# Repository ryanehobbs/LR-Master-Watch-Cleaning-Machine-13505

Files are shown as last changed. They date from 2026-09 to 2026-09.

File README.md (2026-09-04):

# L&R Master Watch Cleaning Machine — Restoration (S/N 13505)

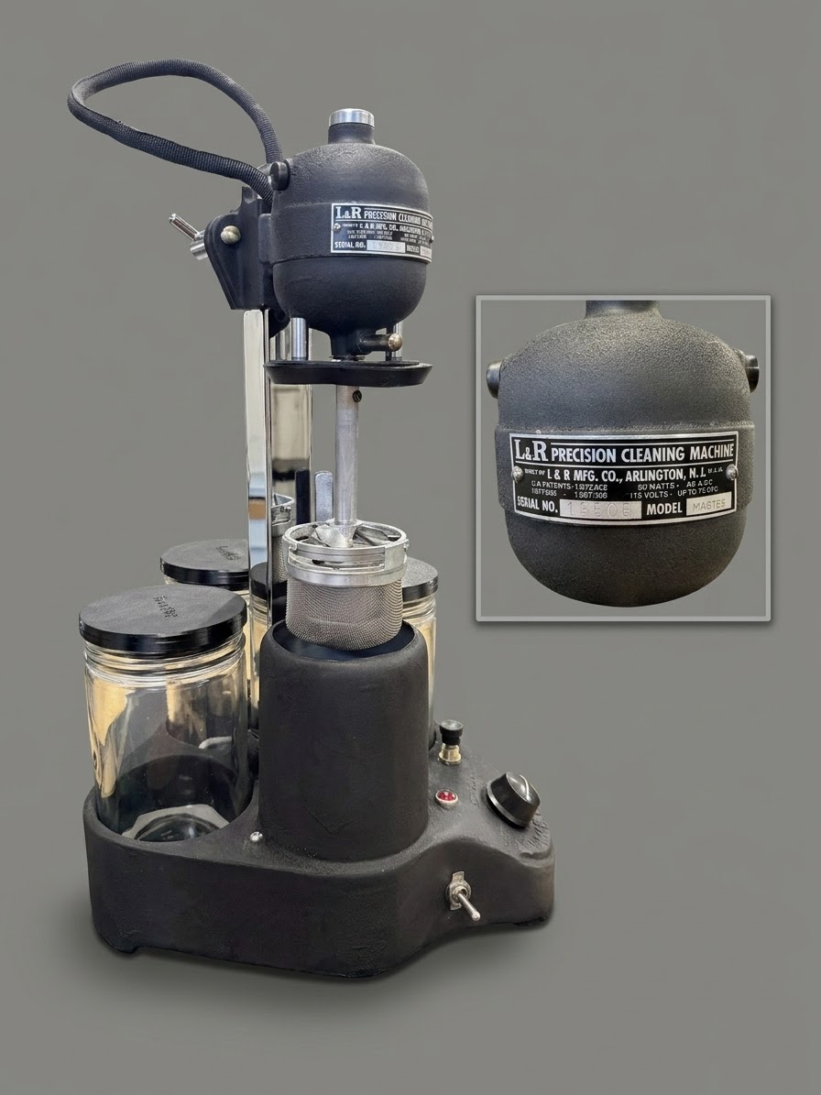
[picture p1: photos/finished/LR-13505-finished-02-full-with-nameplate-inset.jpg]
The restored L&R Precision Cleaning Machine, Model Master, Serial No. 13505 — fully rebuilt and working, with the motor-head data nameplate inset.


Open-source restoration and reverse-engineering of a vintage **L&R Mfg. Co. Master Watch Cleaning Machine** (Master, Serial 13505; the early oiled-bearing generation). This repository documents the full mechanical, cosmetic, and electrical restoration of the machine — from a seized, previously-modified relic to a **working, safely-grounded, fully-documented** cleaner — and contains a complete set of reverse-engineered engineering drawings and a three-part workshop manual, all produced from direct physical measurement of the specimen.

> **REPRODUCTION DOCUMENTATION** — Not original L&R Mfg. Co. technical publications. All drawings, dimensional data, and procedures were reverse-engineered from direct physical work on specimen S/N 13505. Curated by Hobbs R.E., 2026. For restoration reference only.

## Project Status

**🏁 The machine is fully restored and functional.** Both the motor/power head and the control unit are complete and bench-verified running on mains — the motor runs and reverses, the rheostat controls speed, the heater and pilot work, and the wiring passed a full cold-check before first power-on.

| Area | Status |
|---|---|
| **Mechanical restoration** | ✅ Complete — housing refinishing, ultrasonic cleaning, gasket conditioning, sleeve-bearing & wick overhaul, full reassembly |
| **Cosmetic refinishing** | ✅ Complete — motor housings + control-unit casting in VHT wrinkle finish; chrome re-plated; cast lettering restored |
| **Electrical** | ✅ Complete — meter-verified as-found circuit, then a **modern 3-wire grounded rewire** (silicone wire, Wago lever-nut junctions, chassis ground bond); Stage-0 cold-checks passed; commissioned |
| **Dimensional dataset** | ✅ Complete — motor/power head + control unit (base casting, carrier); all confidence-labeled |
| **Engineering drawings** | ✅ Complete — **16-sheet package** (component, exploded, and electrical) on a common master template |
| **Workshop manual** | ✅ First draft — all three parts (Operating / Maintenance / Restoration) |
| **Publication polish** | ⬜ In progress — manual compile, final photos, LICENSE + git init |

## The Machine

A vintage universal-series-motor watch cleaning machine: a mesh basket of disassembled watch parts is spun (forward and reverse) through solvent and rinse jars, then dried in a heated chamber. The motor head rides a swiveling carrier to index the basket over each station.

This restoration preserves the original mechanical character and appearance while **modernizing the electrical system for safety and serviceability** — the original was an ungrounded 2-wire design with a live "green" wire and no earth ground, and the specimen showed prior amateur rework. The rebuild adds a 3-wire grounded cord, a chassis ground bond, high-temp silicone wire, and serviceable lever-nut junctions; every deviation from original is documented.

Designed by **Frank Regero** and built by **L&R Mfg. Co.**; the machine embodies U.S. Patents **1,817,266** (1931), **1,872,812** (1932), and **1,907,366** (1933) — all verified, with copies and details in [`reference/patents/`](reference/patents/) (see [`reference/nameplate-and-patents.md`](reference/nameplate-and-patents.md)).

## Repository Layout

| Path | Contents |
|---|---|
| `docs/manual/` | **Workshop manual** — Part I (Operating), Part II (Maintenance & Service), Part III (Restoration), plus the as-performed source logs (`restoration-log.md`, `teardown-log.md`) |
| `docs/dimensions/` | Confirmed dimensional datasets (CSV) — parts dictionaries (BOM) + per-assembly measurements |
| `drawings/components/` | 2D engineering blueprints — motor components (UH / LH / BRG×2 / ARM / STR / HW / SPN / PLT / BSK), the motor-mount carrier (NCK-002), and the base casting (LR-BASE-001) |
| `drawings/exploded/` | Exploded assembly drawings — EXP-001 (2D profile) + EXP-002 (3D axonometric) |
| `drawings/electrical/` | Schematics — LR-ELEC-002 (verified as-found) + LR-ELEC-003 (as-built 3-wire grounded rewire) |
| `drawings/source/` | Plain-text (`.svg.txt`) snapshots of each drawing (1:1 with the live SVGs) |
| `photos/` | Bench documentation photos by subsystem (housing, armature, bearings, stator-wiring, gasket, basket, hardware, base-refinish, control-unit) |
| `reference/` | External reference material (vintage manuals, archive PDFs, styling references) |
| `archive/` | Superseded drafts and working material — **not part of the published project** (git-ignored) |
| `CLAUDE.md` | Master project log / engineering state (single source of truth) |

## Conventions

- Every physical component carries a canonical **Part ID** (e.g. `UH-003`, `ARM-006`, `STR-002`, `BAS-006`, `NCK-002`) defined in the parts dictionaries under `docs/dimensions/`. All drawings and docs reference parts by ID.
- Dimensions are labeled **(CONFIRMED)** / **(EST.)** / **(SYN)** / **(REF)** for measurement provenance.
- Because no original L&R manual for this machine was obtained, operating/maintenance procedures are labeled **best-judgment** (reconstructed from the mechanism), not factory-verified.
- Engineering-drawing pipeline: dimensions captured to CSV → drawings rendered on a 1200×800 master template → each kept as a `.svg.txt` source snapshot.

## License

Licensed under the **Creative Commons Attribution 4.0 International License (CC BY 4.0)** — see the [`LICENSE`](LICENSE) file. In short: you may use, adapt, and redistribute the material (including commercially), provided you give appropriate credit.

Suggested attribution: *"L&R Master Watch Cleaning Machine Restoration (S/N 13505) by Hobbs R.E., licensed under CC BY 4.0."*

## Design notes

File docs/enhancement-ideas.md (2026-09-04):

# Enhancement Ideas — Optional Modernizations (NON-ORIGINAL)

> **Parking lot, orthogonal to the main restoration.** These are *optional* electrical enhancements discussed as hypotheticals — **not** part of the faithful as-found restoration. None are committed. Guiding rule: **anything done here must keep the as-found design intact/restorable** (the verified `LR-ELEC-002` schematic is the reference), and everything must fold into the grounded, fused **R-5 rewire** — never the original 2-wire ungrounded scheme. Document any that get built as *enhancements*, clearly labeled non-original, in the shop manual.

Status legend: 💡 idea only · 🔬 evaluating · ✅ adopted into R-5 · ❌ declined

---

## 1. 💡 Automatic forward/reverse module
**Goal:** machine cycles motor forward ↔ reverse on its own, no operator input (manual plunger reversing still available).

**Why it's easy here:** reversing = which field lead is hot (white/a = forward, black/c = reverse), sharing one hot common. Anything that alternates hot between those two leads on a timer = auto-reverse. Rheostat (speed/OFF) and the armature/green return are untouched.

**Core:** one **SPDT relay** replicates the plunger (COM = hot, throws = white / black) + a **repeat-cycle timer** driving the coil.
- Timer options: (a) off-the-shelf adjustable **repeat-cycle timer relay** (cheapest); (b) **microcontroller (Arduino/ESP) + relay board** (most flexible); (c) **vintage cam/drum timer** (synchronous motor + cam — period-correct, more work).

**Engineering cautions (make it last):**
- **Coast pause between directions** — do NOT slam a spinning universal motor into reverse (big current spike + brush arcing). Sequence: forward → OFF (coast) → reverse → OFF → repeat.
- **Size relay contacts for INRUSH** (several× running), not just running current (<1 A bench). Suggest 8–10 A / 250 V contacts.
- **Snubber** across the contacts (RC) or an MOV — tames the inductive motor arc, big contact-life win.
- Mains-powered → on the grounded/fused R-5 system, enclosed.
- Optional: keep the manual plunger as a **manual/auto selector** or override.

---

## 2. 💡 Master power switch (fixes "always live when plugged in")
**Problem (documented):** no master switch — the hot rail (N2) is energized the moment the cord is plugged in; only the rheostat (motor) and toggle (heater) gate their branches.

**Fix:** a switch in the **HOT (line) conductor at the inlet, upstream of N2.** Open = whole machine dead.
- **Switch the HOT** specifically (not neutral). SPST in the hot leg = standard. **DPST** (hot + neutral) = full isolation, "belt and suspenders."
- Rheostat + heater toggle remain as downstream sub-controls (Master ON → then run motor / heater).
- **Sizing:** carries the TOTAL machine current — size for the sum with margin (~6–10 A / 250 V; measure total draw first).

**Recommended single-part solution:** a **switched + fused IEC inlet module** (C14 power-entry w/ integral rocker switch + fuse holder) — gives the **grounded inlet + master switch + fuse** in one, pairs perfectly with the R-5 grounded cord. Vintage-look alternative: a bat-handle toggle (matches the Arrow H&H aesthetic) + separate inline fuse.

**Nice touch:** a **power-ON indicator** (the existing red jewel DS1 is the HEATER indicator, not a mains-on light) — an illuminated master switch or a small neon shows the machine is live.

---

## 3. 💡 Fusing — would a 3 A fuse work?
**Estimated steady-state total ≈ 1.6 A:** heater R1 0.55 A + lamp DS1 0.05 A + motor **≤ ~1 A** (inferred: the original plunger that carries the motor is rated **1 A**/125 V, so motor running ≤ ~1 A; the 3 A/250 V toggle on the ~0.6 A heater branch agrees).

**→ A 3 A fuse is reasonable** (~1.9× headroom on steady-state; 360 W capacity vs ~190 W load). **BUT:**
- **Use a SLOW-BLOW (time-delay / "T") fuse**, NOT fast-blow — the universal motor's startup **inrush** (several× running, brief) will nuisance-trip a fast 3 A. Slow-blow rides through inrush and still protects against real overload/short.
- **Measure first** (Kill-A-Watt): if steady-state ~1.5–2 A → **3 A slow-blow**; if it runs hotter (>~2.4 A) → step to **4–5 A slow-blow** (still well under 16 AWG ampacity ~10 A+).
- The fuse protects **the machine/its wiring** from a fault; the **house breaker** protects the building wiring (complementary). A fuse close to the load protects far better than the 15–20 A house breaker alone.

---

## Synergy note
Ideas 2 + 3 + the R-5 grounded rewire combine cleanly into **one switched-fused grounded IEC inlet** (ground + master switch + slow-blow fuse + new cord). Idea 1 (auto-reverse) is independent and bolts onto the white/black field leads downstream. If any are adopted, capture them as labeled non-original enhancements and update R-5 + the manual.

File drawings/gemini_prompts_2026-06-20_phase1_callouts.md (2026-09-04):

# Gemini Rev-Bump Prompts — Phase 1 Drawing Callouts (2026-06-20)

Purpose: add three parts that are in the BOM/logs but not yet on the engineering sheets —
**BRG-011** (lower-housing retaining ring), **ARM-011 ×3 + ARM-012 ×1** (phenolic end-float washers).

**Feed each prompt to Gemini together with the current SVG named in the prompt.** After export:
strip any `.svg.svg` double extension; no `--` (double hyphen) inside SVG comments; keep the 1200x800
master template + standard title block; bump the Rev letter in the title block and add the revision note.

**Standard title-block fields (unchanged):** Date June 12 2026 · Product L&R Precision Cleaning Machine ·
Model Master · Serial 13505 · Manufacturer L&R MFG. CO. · Engineer Hobbs R.E.
**Reproduction annotation** must remain on every sheet.

---

## 1) BRG-002 Lower Bearing — Rev B → Rev C
Source file: `drawings/components/BRG-002_Lower_Bearing_Rev_B.svg`

Add the bottom-of-pocket retaining ring that seats below this bearing in the lower housing:

- New part: **BRG-011 — Metal Retaining Ring** (lower housing only).
- Dimensions (all CONFIRMED): **OD 0.500"**, **ID 0.295"**, **thickness 1/16" (0.0625")**.
- Function/placement: a friction-fit flat metal ring installed at the very bottom of the lower-housing
  bearing pocket, capturing the small felt washer (BRG-010) and retaining the bearing stack. It is
  tapped flush with a brass punch on install.
- Draw it as a small flat ring in section + plan, with a leader callout `BRG-011 METAL RETAINING RING —
  OD 0.500" / ID 0.295" / THK 1/16" (CONFIRMED)`, positioned at the bottom of the bearing-pocket stack.
- Add a note: "BRG-011 is LOWER housing only; the upper housing has no bottom retaining ring."
- Title block: Rev C. Revision note: "Rev C: added BRG-011 retaining ring callout (bottom of pocket)."

---

## 2) LH-001 Lower Housing — Rev E → Rev F  (optional if BRG-002 Rev C covers it)
Source file: `drawings/components/LH-001_Lower_Housing_Rev_E.svg`

In the bearing-pocket cross-section, show **BRG-011** seated at the base of the pocket:

- Same part/dims as above (OD 0.500" / ID 0.295" / THK 1/16", CONFIRMED).
- Place it at the bottom of the pocket below where BRG-002 + felt washers sit; thin flat ring in the
  section view, with a leader `BRG-011 RETAINING RING (FRICTION-FIT)`.
- Title block: Rev F. Revision note: "Rev F: show BRG-011 retaining ring seated at base of bearing pocket."

---

## 3) ARM-001 Armature Assembly — Rev D → Rev E
Source file: `drawings/components/ARM-001_Armature_Assembly_Rev_D.svg`

Add the lower-journal phenolic end-float washer stack on **SHF-003** (ARM-010 is already shown):

- New parts (all phenolic, non-conductive, oil/heat-resistant; bore slip-fits SHF-003 Ø0.280"):
  - **ARM-011 — Phenolic End-Float Washer (Large), QTY 3**: OD **0.630"**, bore **0.285"**, thickness **0.017"** each.
  - **ARM-012 — Phenolic End-Float Washer (Small), QTY 1**: OD **0.500"**, bore **0.285"**, thickness **0.016"**.
  - Combined 4-washer stack thickness **0.065"** (CONFIRMED).
- Placement/order on the lower journal SHF-003: these are INTERNAL washers that seat ON TOP of the
  lower bearing (BRG-002). Order, from the bearing toward the armature: **ARM-012 (small, closest to the
  bearing) → ARM-011 ×3**. Draw them as a thin slip-on washer stack on the lower journal, between the
  fan-end collar (ARM-009) region and the bearing/ARM-010 location.
- Leader callouts: `ARM-011 PHENOLIC WASHER x3 — OD 0.630" / BORE 0.285" / THK 0.017" EA (CONFIRMED)`
  and `ARM-012 PHENOLIC WASHER x1 — OD 0.500" / BORE 0.285" / THK 0.016" (CONFIRMED)`, plus a stack note
  `4-WASHER END-FLOAT STACK = 0.065"; SETS FAN (ARM-007) CLEARANCE ABOVE HOUSING FLOOR`.
- Note to distinguish from ARM-010: "ARM-011/012 are INTERNAL (on top of BRG-002); ARM-010 is the
  EXTERNAL brass slinger below the housing." Keep ARM-010 as already drawn.
- Title block: Rev E. Revision note: "Rev E: added ARM-011 x3 + ARM-012 phenolic end-float washer stack on SHF-003."

---

## 4) EXP-001 Motor Exploded (2D profile) — Rev D → Rev E
Source file: `drawings/exploded/EXP-001_Motor_Exploded_Rev_D.svg`

Insert the 4 phenolic washers into the exploded lower-journal sequence:

- Sequence on the lower journal (top=armature side, going down toward the basket):
  `ARM-001 lower journal → ARM-011 x3 → ARM-012 → BRG-002 (in LH-001) → [journal protrudes] → ARM-010 (external slinger) → SPN-002 spindle …`
- So the 4 washers go BETWEEN the armature lower journal and BRG-002, with **ARM-012 adjacent to BRG-002**
  and the **3x ARM-011 above it**. ARM-010 stays on the far (basket) side of BRG-002/LH-001.
- Draw them as thin discs on the common centerline with leader callouts and Part IDs (ARM-011, ARM-012);
  keep dims compact (`ARM-011 PHENOLIC x3`, `ARM-012 PHENOLIC x1`) — full dims live on ARM-001.
- Title block: Rev E. Revision note: "Rev E: inserted ARM-011 x3 + ARM-012 phenolic washer stack between ARM-001 lower journal and BRG-002."

---

## 5) EXP-002 Motor 3D Exploded (axonometric showcase) — Rev D → Rev E
Source file: `drawings/exploded/EXP-002_Motor_3D_Exploded_Rev_D.svg`

Same insertion as EXP-001, in the 3D axonometric stack:

- Add the 4 phenolic washers as scaled ellipse discs (depth-projected like the other parts) on the lower
  journal, between the armature and BRG-002: **ARM-012 nearest BRG-002, ARM-011 x3 above it.**
- Render them in a phenolic-look finish (reddish-brown/amber, matte) distinct from the brass ARM-010
  slinger and the steel bearing; tether to the central alignment guideline like the other elements.
- Leader callouts with Part IDs (ARM-011 x3, ARM-012 x1); keep ARM-010 as the external brass slinger.
- Title block: Rev E (date stays June 12 2026 per standard). Revision note: "Rev E: added ARM-011 x3 + ARM-012 phenolic end-float washer stack on lower journal."

---

### After Gemini renders (housekeeping)
- Save into `drawings/components/` (sheets 1-3) and `drawings/exploded/` (sheets 4-5); strip `.svg.svg`.
- Archive the superseded Rev D/E/B files to `archive/old_svg/`.
- Refresh the `.svg.txt` source snapshots in `drawings/source/`.
- Update the CLAUDE.md drawing table + REWORK QUEUE (mark BRG-011 / ARM-011/012 callouts DONE).

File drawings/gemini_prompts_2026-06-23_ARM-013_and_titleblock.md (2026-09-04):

# Gemini Rev-Bump Prompts — ARM-013 callout (B2) + title-block rename (B3) — 2026-06-23

Purpose:
- **B2** — add **ARM-013** (upper-journal phenolic end-float washer stack, ×4) to **ARM-001**, **EXP-001**, **EXP-002**. Mirror of the lower-journal ARM-011/012 set added in the 2026-06-20 pass.
- **B3** — correct the title-block model nomenclature **"Mark 1 Master" → "Master"** ("Mark 1/2/3" is collector shorthand, NOT L&R factory nomenclature; only "L&R" / "MASTER" is cast on the machine).

**Feed each prompt to Gemini together with the current SVG named in the prompt.** After export:
strip any `.svg.svg` double extension; no `--` (double hyphen) inside SVG comments; keep the 1200x800
master template + standard title block; bump the Rev letter and add the revision note.

**Standard title-block fields:** Date June 12 2026 · Product L&R Precision Cleaning Machine ·
**Model Master** · Serial 13505 · Manufacturer L&R MFG. CO. · Engineer Hobbs R.E.
**Reproduction annotation** must remain on every sheet.

**⚠️ TWO TITLE-BLOCK FIXES already applied to the other 10 sheets — apply them on these re-renders too:**
1. **DATE must read exactly `June 12, 2026`** (earlier Gemini exports drifted to June 13/14 — do not restamp the current date).
2. **DRAWING TITLE value must NOT overflow into the PART NUMBER / ID cell.** On the header-style title block the "DRAWING TITLE" value (monospace 12px at x=765) was running past the x=965 cell divider over the "PART NUMBER / ID" value at x=975. Constrain it to its cell — keep the full title text but fit it (e.g. `font-size="10px" textLength="185" lengthAdjust="spacingAndGlyphs"`, or shrink the font so the longest title ends before x=955). (EXP-001/002 use a wide title row with no Part Number cell, so no overlap there — just keep the date fix.)

**ARM-013 spec (all CONFIRMED):** phenolic, non-conductive, oil/heat-resistant; **QTY 4, ALL IDENTICAL**
(no 3+1 split, unlike the lower ARM-012). **OD 0.4705"**, **bore 0.2500"** (slip-fit on the upper journal
SHF-002 Ø0.250"), **thickness 0.0175" each**, **4-stack = 0.070"**. Function: end-float / axial-spacing
shim stack on the UPPER journal, riding against the UPPER bearing (BRG-001) at the commutator end — sets
the rotor's top-end axial position (upper-end mirror of the lower ARM-011/012 stack).

---

## 1) ARM-001 Armature Assembly — Rev E -> Rev F   (B2 + B3)
Source file: `drawings/components/ARM-001_Armature_Assembly_Rev_E.svg`

Add the **upper-journal** phenolic end-float washer stack on **SHF-002** (the commutator / upper-bearing end):

- New part: **ARM-013 — Phenolic End-Float Washer (Upper), QTY 4 (all identical)**: OD **0.4705"**, bore
  **0.2500"**, thickness **0.0175"** each; 4-stack **0.070"**.
- Placement/order on the upper journal SHF-002: thin slip-on washer stack near the upper-bearing end,
  riding against **BRG-001** — between the upper brass collar (**ARM-008**) region and the top journal end
  / upper-bearing location. (This is the exact mirror of how ARM-011/012 sit on the lower journal against
  BRG-002.)
- Leader callout: `ARM-013 PHENOLIC WASHER x4 (ALL IDENTICAL) — OD 0.4705" / BORE 0.2500" / THK 0.0175" EA
  (CONFIRMED)`, plus a stack note `4-WASHER END-FLOAT STACK = 0.070"; SETS ROTOR TOP-END AXIAL POSITION
  AGAINST BRG-001`.
- Note to distinguish the three phenolic stacks: "ARM-013 = UPPER journal (against BRG-001); ARM-011 x3 +
  ARM-012 = LOWER journal (against BRG-002); all phenolic, non-conductive." Keep ARM-010/011/012 as drawn.
- **B3 title-block fix:** change the Model field from **"Mark 1 Master" to "Master"** (and any header text
  "MARK 1 MASTER..." to "MASTER...").
- Title block: **Rev F**. Revision note: "Rev F: added ARM-013 x4 phenolic upper-journal end-float washer
  stack on SHF-002 (against BRG-001); model nomenclature corrected to Master."

---

## 2) EXP-001 Motor Exploded (2D profile) — Rev E -> Rev F   (B2 + B3)
Source file: `drawings/exploded/EXP-001_Motor_Exploded_Rev_E.svg`

Insert the 4 upper-journal phenolic washers into the exploded UPPER-journal sequence:

- In the vertical exploded stack (UH-001 -> STR-001 -> BRG-001 -> ARM-001 ...), the upper journal of
  ARM-001 meets **BRG-001**. Insert **ARM-013 x4** on the upper journal **between BRG-001 and the armature
  upper journal** (commutator end) — the mirror of the ARM-011/012 stack already shown on the lower journal
  between ARM-001 and BRG-002.
- Draw as thin discs on the common centerline with a leader callout + Part ID (`ARM-013 PHENOLIC x4`);
  keep dims compact — full dims live on ARM-001.
- **B3 title-block fix:** Model "Mark 1 Master" -> "Master" (and any "MARK 1 MASTER..." header -> "MASTER...").
- Title block: **Rev F**. Revision note: "Rev F: inserted ARM-013 x4 phenolic washer stack between BRG-001
  and the ARM-001 upper journal; model nomenclature corrected to Master."

---

## 3) EXP-002 Motor 3D Exploded (axonometric showcase) — Rev E -> Rev F   (B2 + B3)
Source file: `drawings/exploded/EXP-002_Motor_3D_Exploded_Rev_E.svg`

Same insertion as EXP-001, in the 3D axonometric stack:

- Add the **4 ARM-013 washers** as scaled ellipse discs (depth-projected like the other parts) on the
  upper journal, **between BRG-001 and the armature upper journal** (commutator end): ARM-012/011 stack
  stays on the lower journal.
- Render in a phenolic-look finish (reddish-brown / amber, matte), distinct from brass (ARM-010) and steel
  (bearings); tether to the central alignment guideline like the other elements.
- Leader callout with Part ID (`ARM-013 PHENOLIC x4`). Keep ARM-010 as the external brass slinger and the
  lower ARM-011/012 stack as drawn.
- **B3 title-block fix:** Model "Mark 1 Master" -> "Master" (and any "MARK 1 MASTER..." header -> "MASTER...").
- Title block: **Rev F** (date stays June 12 2026 per standard). Revision note: "Rev F: added ARM-013 x4
  phenolic upper-journal end-float washer stack on the upper journal; model nomenclature corrected to Master."

---

## B3 — title-block rename on the remaining 9 sheets (nomenclature only)
These sheets need ONLY the "Mark 1 Master" -> "Master" correction (no geometry change). Either run them
through Gemini one rev each, OR (faster, deterministic) apply the text substitution directly in the SVG and
bump the rev. Sheets + rev bumps:

| Sheet | Rev bump |
|---|---|
| BRG-001 Upper Bearing | D -> E |
| BRG-002 Lower Bearing | C -> D |
| BSK-002 Mesh Basket | C -> D  *(see special note)* |
| HW-001 External Hardware | F -> G |
| LH-001 Lower Housing | F -> G |
| PLT-001 Platform Seal Deck | C -> D |
| SPN-002 Basket Drive Spindle | C -> D |
| STR-001 Stator Assembly | Q -> R |
| UH-001 Upper Housing | K -> L |

For each: change Model **"Mark 1 Master" -> "Master"**; change any header "MARK 1 MASTER CLEANING MACHINE"
-> "MASTER CLEANING MACHINE" and "MARK 1 MASTER" -> "MASTER". Revision note: "Rev X: model nomenclature
corrected to Master (Mark 1/2/3 is collector shorthand, not factory)."

**⚠️ BSK-002 SPECIAL NOTE — do NOT blind-replace.** BSK-002 carries a technical note:
`Nominal basket dia for this system (Mark 1 Master) = 2 3/4" (2.750");`
Reword to keep the size fact but drop the model-name implication, e.g.:
`Nominal basket dia for this (early/large-basket) generation = 2 3/4" (2.750"); later units used 2 1/4".
(Mark 1/2 = collector shorthand, not L&R factory nomenclature.)`

---

### After Gemini renders (housekeeping)
- Save into `drawings/components/` and `drawings/exploded/`; strip `.svg.svg`.
- Archive superseded files to `archive/old_svg/`.
- Refresh the `.svg.txt` source snapshots in `drawings/source/`.
- Update the CLAUDE.md drawing table + close ledger B2/B3.

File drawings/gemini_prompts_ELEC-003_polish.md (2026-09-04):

# Gemini Prompt — Polish/Render LR-ELEC-003 (Control Unit As-Built Rewire)

**Feed this prompt to Gemini together with the source SVG:**
`drawings/electrical/LR-ELEC-003_ControlUnit_AsBuilt_Rewire_Rev_A.svg`
(or the text snapshot `drawings/source/LR-ELEC-003_ControlUnit_AsBuilt_Rewire_Rev_A.svg.txt`)

After export: strip any `.svg.svg` double extension; no `--` (double hyphen) inside SVG comments; keep it Rev A (this is a cosmetic re-render of an unpublished first issue, not a content change).

---

## PROMPT

You are cleaning up and re-rendering an existing electrical schematic SVG (attached). This is a METER-VERIFIED as-built wiring schematic for a vintage watch-cleaning machine. Produce a polished, professional engineering-schematic version.

**ABSOLUTE RULES — do not change the electrical content:**
- Preserve EVERY connection, wire, and node EXACTLY as in the source. Do not add, remove, reroute, or "correct" any connection. The circuit is verified correct.
- Preserve all node labels exactly: **N1 (neutral), N2 (hot), N3 (heater/lamp return), N4 (motor forward), N5 (motor speed/common), N6 (motor reverse).**
- Preserve all component IDs and values exactly: **R1/CTL-007 (220 Ohm Ohmite P/N 33974, ~65W), DS1/CTL-005 (120V 6W pilot), S1/CTL-003 (plunger transfer switch, a=forward/OUT, c=reverse/IN, d+b=hot common), S2/CTL-004 (heater switch, SPST), RV1/CTL-001 (425 Ohm IRC rheostat, wiper + CCW, full CCW=OFF), M1 (universal series motor), P1/CTL-008 (3-wire NEMA 5-15P cord).**
- Preserve the WIRE COLORS exactly (they are meaningful): BLACK=hot(N2), WHITE/gray=neutral(N1), GREEN=ground only, RED=motor forward(N4), BLUE=motor reverse(N6), YELLOW/amber=motor speed-common(N5), RED-with-band(dashed)=heater/lamp return(N3).
- Preserve the ground system: 3-wire grounded inlet (L/N/G), the W-6 chassis bond (green ring lug to bare casting) drawn as a ground symbol.
- Preserve the Wago 221 junction callouts at N2 (5-port), N1 (3-port), N3 (3-port), and the "loom green = LIVE common, band red" caution at N5.
- Preserve ALL notes text (1 through 6) and the color key verbatim in meaning.

**WHAT TO IMPROVE (visual only):**
- Clean, evenly-spaced layout; eliminate any label overlaps or crowding; align components on a tidy grid.
- Use proper schematic symbols: resistor zigzag for R1 and the rheostat RV1 (with wiper arrow), an X-in-circle for the lamp DS1, a labeled box for the plunger transfer switch S1, a standard SPST symbol for S2, a circle for motor M1, a standard earth-ground symbol for the chassis bond.
- Make the two horizontal rails (N2 hot top, N1 neutral bottom) clean and clearly labeled; show the three Wago distribution nodes as neat labeled connectors.
- Keep it clean line-art on white; colored strokes only for the wire colors above. Legible monospaced or clean sans-serif labels.

**HOUSE STANDARD (keep):**
- Canvas 1200 x 820 engineering border with a header strip across the top reading: "L&R PRECISION CLEANING MACHINE  —  CONTROL UNIT  —  AS-BUILT 3-WIRE GROUNDED REWIRE (R-5)" and "LR-ELEC-003  Rev A" at the right.
- Keep the NOTES block and the TITLE BLOCK (bottom). Title-block fields: Product = L&R Precision Cleaning Machine; Model = Master; Serial = 13505; Manufacturer = L&R MFG. CO.; Engineer = Hobbs R.E.; Date = June 12, 2026; Drawing/Rev = LR-ELEC-003 / Rev A — FIRST ISSUE (as-built + commissioned).
- Keep the REPRODUCTION annotation verbatim: "REPRODUCTION DOCUMENT — Not an original L&R Mfg. Co. technical publication. Reverse-engineered from direct physical measurement of specimen S/N 13505. Curated by Hobbs R.E., 2026. Reference only."
- Output valid SVG. No `--` inside SVG comments.

Return only the finished SVG.

---

### After Gemini renders (housekeeping)
- Save into `drawings/electrical/`; strip any `.svg.svg` double extension.
- If content unchanged (cosmetic only), keep the same filename/Rev A and archive the Claude-authored source to `archive/old_svg/` if you prefer the Gemini render as the master; OR keep both and note which is the published master.
- Refresh the `.svg.txt` source snapshot in `drawings/source/`.
- Sanity-check: every node (N1-N6), every value, every wire color, and all 6 notes must match the original. If Gemini altered any connection or label, reject and re-run.

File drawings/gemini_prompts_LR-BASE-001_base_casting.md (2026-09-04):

# Gemini Prompt — LR-BASE-001 Base Casting Rev B (route A to B)

**Feed this prompt to Gemini together with the draft seed:**
`drawings/source/LR-BASE-001_Base_Casting_Rev_B_DRAFT.svg.txt`

After export: strip any `.svg.svg` double extension; no `--` (double hyphen) inside SVG comments; save as
`drawings/components/LR-BASE-001_Base_Casting_Rev_B.svg` (drop the DRAFT/SEED wording); keep master template + title block.
Remove any `[cite: N]` citation artifacts Gemini may insert into text.

**Standard title-block fields:** Date June 12 2026 · Product L&R Precision Cleaning Machine · Model Master ·
Serial 13505 · Manufacturer L&R MFG. CO. · Engineer Hobbs R.E. **Reproduction annotation stays on the sheet.**

---

## PROMPT

Render a clean, professional vintage-style mechanical engineering drawing of the part in the attached draft SVG: the **LR-BASE-001 Base Casting** of an L&R Master watch-cleaning machine. The draft is a rough dimensioned seed — reproduce the SAME part and SAME dimensions, but render it properly: accurate proportions to the dims below, clean orthographic views, professional dimensioning, and cast-part shading (sand-cast: soft radiused edges, draft angles, NO crisp machined corners except the drilled/tapped holes and the square post socket).

**What the part is (for correct form):**
A large sand-cast aluminium body. Rounded-rectangle plan with a squared rear wall (rounded corners) and STRAIGHT left/right sides; the bottom transitions via a gentle S-curve into a forward, teardrop/paddle **control tongue**, then curves to a broad rounded bottom. It holds **4 wells in a 2x2 square grid** (4.500" pitch): the front-left is the **HEATER WELL** (a tall raised tube), the other three are equal **JAR BAYS**. A central **square post socket** (BAS-006) sits between the 4 wells. The forward **tongue** carries the controls: a rheostat knob on a FLAT face (no recess), a jewel lamp (upper-left), a plunger button (upper-right), and a toggle on the LEFT SIDE FACE; cast relief lettering "L&R MASTER" in a smile arc plus "OFF" and "ON" with a sweep arrow. The casting rests on **3 raised feet** (2 rear corners + 1 front under the tongue). An AC grommet hole is on the REAR wall.

**Views to draw:**
- **PLAN VIEW** (top-down, rear wall at top, forward tongue at bottom): body outline, the 4 wells (heater front-left, 3 jar bays), central square post socket, the tongue with its control holes + cast lettering, and the 3 feet.
- **FRONT ELEVATION**: the tall heater tube rising from the body, the body block, jar-well rims, the forward tongue ramp, the 3 feet, and the rear-wall grommet.
- (optional) a SIDE ELEVATION or partial SECTION through the heater well if it aids clarity.

**Dimensions (all CONFIRMED by caliper unless noted) — label on the views:**
- Body: width **8.875"** (L-R) x depth **9.375"** (rear to well-cluster front, excl. tongue) x height **2.875"**; overall depth with tongue **12.875"**; wall thickness **0.280"**; feet **0.350"** proud (3 pads).
- Wells (2x2 grid): **4.500"** pitch (X and Y, square); cluster diagonal **6.364"**.
- Jar bays (x3): bore **3.955"**, depth **1.925"**, floor **0.800"** above base bottom, wall **0.300"**; jar OD ref 3.830".
- Heater well (front-left): total height **7.375"**, tube above body **4.500"**, top lip ID **3.268"**, interior bore **3.800"** (NOTE: SMALLER than the jar bays, it is the taller well not wider), bore depth rim to cast-top ledge **4.9075"**, lower section (R1 gap) **2.550"**, wall **0.120"**, floor opening **3.80"** (full bore), R1 bracket screw hole **0.190"**.
- Post socket BAS-006: square inside across-flats **1.300"** (fit-critical), depth **2.9035"** (near full body height); NO oil/access bore; retained by **6 screws in 2 groups** (4 SET screws: one large 3/8 + three 1/2in #10; plus 2 POST-penetrating screws ~#5-6).
- Tongue BAS-004: widths **4.80"** (at body) / **3.80"** (middle) / **2.00"** (front tip); projection **3.500"**; face ramp **26.6 deg**; rheostat on a FLAT face (NO cast recess); rheostat shaft hole **0.395"**; jewel, plunger, and toggle holes **0.490"** each.
- Grommet BAS-007: on the REAR wall, centered (~4.5" lateral); hole center **1.000"** up from the foot plane; stepped bore **0.400"** inner / **0.595"** outer.
- Cast relief lettering BAS-005 (for repro): "L&R MASTER" smile arc chord **3.138"**, letter cap height **0.489"**, struck ~R**2.75"**; "OFF" width **0.63"**; "ON" sweep arrow ~**0.625"** long. Typeface: mid-century condensed sans (Franklin Gothic Condensed / News Gothic).

**Confidence labels:** `(CONFIRMED)` on measured dims. Note the corrections vs the old Rev A plan view: heater bore is SMALLER than jars (not larger); rheostat is on a FLAT face (no recess); NO oil bore in BAS-006; the body is ROUNDED sand-cast (not squared).

**House standard:**
- Canvas **1200 x 800** engineering border; header strip top; title block bottom-right; notes box bottom-left.
- Header: "LR-BASE-001  BASE CASTING  —  L&R MASTER 13505" + "LR-BASE-001 Rev B" at right.
- Reproduction annotation verbatim: "REPRODUCTION DOCUMENT — Not an original L&R Mfg. Co. technical publication. Reverse-engineered from direct physical measurement of specimen S/N 13505. Curated by Hobbs R.E., 2026. Reference only."
- Title-block fields as listed; Drawing/Rev = LR-BASE-001 / Rev B — supersedes the old plan-view Rev A.
- Canonical Part IDs where labeled (BAS-002 heater well, BAS-003 jar bay, BAS-004 tongue, BAS-005 lettering, BAS-006 post socket, BAS-007 grommet).
- Output valid SVG. No `--` inside comments. No `[cite: N]` artifacts in text.

Return only the finished SVG.

---

### After Gemini renders (housekeeping)
- Save into `drawings/components/` as `LR-BASE-001_Base_Casting_Rev_B.svg`; strip `.svg.svg`; remove any `[cite: N]`.
- Refresh the `.svg.txt` source snapshot; archive this DRAFT seed to `archive/old_svg/` for 1:1 parity.
- The old root-folder plan-view `LR-BASE-001_Base_Casting.svg` (Rev A) is superseded; archive it too.
- Update the CLAUDE.md drawing table (add LR-BASE-001 Rev B) + memory.
- Sanity-check: all dims above present + correct; corrections reflected; Part IDs correct.

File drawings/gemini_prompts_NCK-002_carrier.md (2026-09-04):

# Gemini Prompt — NCK-002 Motor-Mount Carrier (new drawing, route A to B)

**Feed this prompt to Gemini together with the draft seed SVG:**
`drawings/components/NCK-002_MotorMount_Carrier_Rev_A_DRAFT.svg`

After export: strip any `.svg.svg` double extension; no `--` (double hyphen) inside SVG comments; save as
`drawings/components/NCK-002_MotorMount_Carrier_Rev_A.svg` (drop the DRAFT/SEED wording in the header + title block); keep the master template + standard title block.

**Standard title-block fields:** Date June 12 2026 · Product L&R Precision Cleaning Machine · Model Master ·
Serial 13505 · Manufacturer L&R MFG. CO. · Engineer Hobbs R.E. **Reproduction annotation stays on the sheet.**

---

## PROMPT

Render a clean, professional vintage-style mechanical engineering drawing of the part in the attached draft SVG: the **NCK-002 Motor-Mount Carrier** for an L&R Master watch-cleaning machine. The draft is a rough dimensioned seed — reproduce the SAME part and SAME dimensions, but render it properly (accurate proportions to the dims below, clean orthographic views, professional dimensioning, cast-part shading with soft radii and draft angles).

**What the part is (for correct form):**
A small cast bracket. A **square sleeve** (socket) slides onto the square top of the post (NCK-001). The BOTTOM of the sleeve is a **split clevis clamp**: a saw-cut slot through one side, closed by a cross screw (NCK-003) to grip the post. The TOP of the carrier is an **open concave saddle** that cradles the ROUND upper motor housing (UH-001). Two flat **mount ears** wing out to the sides, each with a **counterbored** hole; two screws pass through into the round housing's two mount holes to retain the motor. A small **alignment tab / key** protrudes from one edge of the sleeve. Sand-cast aluminium: soft radiused edges, draft angles, no crisp machined corners except the bored/tapped holes and the square bore.

**Views to draw (2 or 3 orthographic):**
- **TOP / PLAN** (looking down the post axis): square sleeve outline, the central square bore, the two mount ears with their counterbored holes, the alignment tab, and the saddle opening.
- **FRONT ELEVATION**: the sloped hump profile (low at the ends, high at the center saddle), the concave saddle notch at top, the square sleeve, and the split clevis clamp at the base with its tightener holes + slot.
- **(optional) SIDE ELEVATION or a section** through the sleeve/clevis if it helps clarity.

**Dimensions (all CONFIRMED by caliper unless noted) — label these on the views:**
- Square bore (post fit), inside across-flats: **1.26"** (fit-critical)
- Square sleeve body: outer width **2.232"**, body height **~1.67"**
- Overall length across the two ears: **3.04"**
- Mount holes (x2), stepped/counterbored: **0.300-0.305" thru / 0.565" counterbore** (seats screw head); spacing **2.30" center-to-center**
- Alignment tab: base width **0.300"**, tip width **0.1975"** (tapered), protrusion/height **0.3905"**
- Split clevis clamp: total opening width **0.622"**, internal slot gap **0.102"**; tightener holes **0.450" clearance** (one ear) / **0.305" threaded** (other ear) for NCK-003
- Overall envelope: length **3.04"** x depth **2.232"** x height **0.95" at the ends sloping to 1.50" max at the center**; mounting-ear plate thickness **0.25"**
- Saddle cradle: **open concave** (no bore dim); concave radius = the OD of the round upper housing UH-001 it seats (**~R1.60"**, from UH-001 outer dia 3.200") — label as `(SYN, = mating UH-001 OD)`.

**Confidence labels:** put `(CONFIRMED)` on the measured dims; the saddle radius is `(SYN)`.

**House standard:**
- Canvas **1200 x 800** engineering border; header strip top; title block bottom-right, notes box bottom-left.
- Header: "NCK-002  MOTOR-MOUNT CARRIER  —  L&R MASTER 13505" + "NCK-002 Rev A" at right.
- Notes: keep the function notes (1-3) and the reproduction annotation verbatim.
- Title-block fields as listed above; Drawing/Rev = NCK-002 / Rev A — FIRST ISSUE.
- All part callouts use canonical IDs (NCK-002 the carrier, NCK-001 post, NCK-003 clamp screw, UH-001 upper housing).
- Output valid SVG. No `--` inside SVG comments.

Return only the finished SVG.

---

### After Gemini renders (housekeeping)
- Save into `drawings/components/` as `NCK-002_MotorMount_Carrier_Rev_A.svg`; strip any `.svg.svg`; delete/keep the DRAFT seed as you prefer.
- Refresh the `.svg.txt` source snapshot in `drawings/source/`.
- Update the CLAUDE.md drawing table (add NCK-002 Rev A) + memory.
- Sanity-check: all dims above present + correct; Part IDs correct.

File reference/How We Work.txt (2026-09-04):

Ai Agents

Goal: Create a open source project pertaining to L&R Watch Cleaning Restoration that I can publish to GitHub.

Gemini

* Will be used to draft mechanical drawings
* Back and forth can be done via markup
* Help draft vintage L&R workshop manual based on our restoration project
** Requires accurate measurement readings
** Procedure explanations for evaluation, removal, installation etc. 

Claude

* Will be used to draft electrical layouts
* Test plans for electrical work
* Procedure for break down and restoration steps this means how we removed finish, how we applied VHT.
* Tracking project steps and status it knows what we have done and what is left to do

Current Status

* Motor housing has been refinished
* Need to punch out felt washers and re-install bearings. But before that I want to accurately acquire measurements for workshop manual.

Gaps
* I need a better way to document steps/procedures for when I took something apart. What tools did I use, what tricks did I apply.  
* Need to ensure starting with motor housing I document how re-installation is done.

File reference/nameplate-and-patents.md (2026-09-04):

# Data Nameplate & Patents — Specimen S/N 13505

> **REPRODUCTION DOCUMENT** — transcribed directly from the motor-head data nameplate of specimen S/N 13505. Curated by Hobbs R.E., 2026. For restoration reference only.

Source photos: `photos/finished/LR-13505-finished-02-full-with-nameplate-inset.jpg`, `photos/finished/LR-13505-finished-03-motorhead-nameplate.jpg`.

## Nameplate transcription
| Field | Value |
|---|---|
| Product | **L&R PRECISION CLEANING MACHINE** |
| Manufacturer | Made by **L&R MFG. CO., Arlington, N.J., U.S.A.** |
| Serial No. | **13505** |
| Model | **MASTER** |
| Rating | **60 WATTS · AC & DC** |
| Voltage | **115 VOLTS · up to 75 cyc.** ("cyc." = cycles/second = Hz) |
| U.S. Patents | **1,872,812 · 1,817,266 · 1,907,366** |

## U.S. Patents listed on the plate
Three patents are cast/stamped on the nameplate — all **"Watch Cleaning Machine"** patents by **Frank Regero**, the machine's designer (assigned to L&R Mfg. Co.). **All three are now verified from the granted patent documents** (copies in `reference/patents/`). ✅ **Complete set.**

| Patent No. | Title | Inventor | Filed | Granted | Status |
|---|---|---|---|---|---|
| **1,817,266** | Watch Cleaning Machine | Frank Regero | Aug. 5, 1929 | **Aug. 4, 1931** | ✅ **VERIFIED** — PDF `reference/patents/US-1817266-A.pdf` |
| **1,872,812** | Watch Cleaning Machine | Frank Regero | July 11, 1930 | **Aug. 23, 1932** | ✅ **VERIFIED** — PDF `reference/patents/US-1872812-A.pdf`; number molded into the gasket |
| **1,907,366** | Watch Cleaning Machine | Frank Regero | Dec. 13, 1930 | **May 2, 1933** | ✅ **VERIFIED** — PDF `reference/patents/US-1907366-A.pdf` |

### What each patent covers (from the granted drawings)
- **1,817,266 (1931) — the foundational machine.** Fig. 1 shows the whole architecture we restored: a vertical support post, a swiveling operating arm/handle (to index the head over each station), the motor mounted up top, and a **mesh basket that lowers into the jars**. Fig. 5 details the two-piece screen basket with a clamped lid; Fig. 4 shows the motor end with its cooling fan. This is the core watch-cleaning-machine concept.
- **1,872,812 (1932) — speed control + star basket.** Fig. 1 shows a toothed **speed-control disk** (ref. 29/30) mounted below the motor on the post, and Fig. 2 shows the **six-point star basket** profile seated in a jar — the mechanical DNA of this machine (the rheostat-driven variable speed and the fluted basket). This is the number molded into the specimen's gasket.
- **1,907,366 (1933) — the spherical motor housing + refinements.** Fig. 1 shows the distinctive **round/ball motor housing** (matching our upper housing UH-001) on the swivel arm, with the basket lowering into a jar; Fig. 1a shows a star/hex basket profile. This is the later improvement patent that gives the Master its familiar spherical motor dome.

> **Historical note.** Both verified patents name **Frank Regero** as inventor — the designer behind the L&R watch-cleaning machine line. The progression 1,817,266 (filed 1929) → 1,907,366 (filed 1930) tracks the evolution from the general machine to the spherical-motor "Master" form factor this specimen represents.

> **Plate set complete.** All three nameplate patents are verified and their granted-document PDFs are filed in `reference/patents/`. No further patents apply to specimen 13505.

### Beyond this machine — the wider L&R / Regero portfolio (optional)
These are **later** L&R watch-cleaning patents that are **NOT marked on specimen 13505** (they postdate its 1933 plate). Collect only if you want the full historical portfolio; they do not apply to this machine:
- **US 2,081,142**, **US 2,150,560**, **US 2,184,020** (watch *and jewelry* cleaning), **US 2,277,919**, **US 2,692,603** — assorted later "Watch Cleaning Machine" improvements.
- **US 861,990** (1907) — a much earlier, unrelated watch-cleaning machine (different inventor); historical prior-art context only.

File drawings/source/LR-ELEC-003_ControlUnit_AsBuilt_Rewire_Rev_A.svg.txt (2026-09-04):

<svg xmlns="http://www.w3.org/2000/svg" viewBox="0 0 1200 820" width="100%" height="100%">
  <defs>
    <style>
      .bg { fill: #ffffff; }
      .border-main { stroke: #0f172a; stroke-width: 2; fill: none; }
      .border-thin { stroke: #334155; stroke-width: 1; fill: none; }
      .border-sub { stroke: #64748b; stroke-width: 1; fill: none; }
      .header-bg { fill: #f8fafc; stroke: #0f172a; stroke-width: 2; }
      .card-bg { fill: #ffffff; stroke: #cbd5e1; stroke-width: 1; rx: 4; }
      
      .w-blk { stroke: #0f172a; stroke-width: 2.2; fill: none; stroke-linecap: round; stroke-linejoin: round; }
      .w-wht { stroke: #64748b; stroke-width: 2.2; fill: none; stroke-linecap: round; stroke-linejoin: round; }
      .w-grn { stroke: #16a34a; stroke-width: 2.2; fill: none; stroke-linecap: round; stroke-linejoin: round; }
      .w-red { stroke: #dc2626; stroke-width: 2.2; fill: none; stroke-linecap: round; stroke-linejoin: round; }
      .w-blu { stroke: #2563eb; stroke-width: 2.2; fill: none; stroke-linecap: round; stroke-linejoin: round; }
      .w-yel { stroke: #d97706; stroke-width: 2.2; fill: none; stroke-linecap: round; stroke-linejoin: round; }
      .w-red-dash { stroke: #dc2626; stroke-width: 2.2; stroke-dasharray: 5 4; fill: none; stroke-linecap: round; stroke-linejoin: round; }
      
      .comp-body { stroke: #0f172a; stroke-width: 2; fill: none; stroke-linecap: round; stroke-linejoin: round; }
      .comp-box { stroke: #0f172a; stroke-width: 1.5; fill: #f8fafc; stroke-dasharray: 4 3; }
      
      .node-dot { fill: #0f172a; stroke: none; }
      .term-dot { fill: #ffffff; stroke: #0f172a; stroke-width: 2; }
      
      .wago-tag { fill: #fffbeb; stroke: #d97706; stroke-width: 1.2; rx: 3; }
      .wago-txt { font-family: 'Consolas', 'Menlo', 'Monaco', monospace; font-size: 11px; font-weight: bold; fill: #b45309; text-anchor: middle; }
      
      .node-pill { fill: #0f172a; rx: 3; }
      .node-pill-txt { font-family: 'Consolas', 'Menlo', 'Monaco', monospace; font-size: 12px; font-weight: bold; fill: #ffffff; text-anchor: middle; }
      
      .txt-hd { font-family: 'Segoe UI', system-ui, -apple-system, sans-serif; font-weight: 800; font-size: 16.5px; fill: #0f172a; letter-spacing: 0.5px; }
      .txt-hd-right { font-family: 'Consolas', 'Menlo', 'Monaco', monospace; font-weight: bold; font-size: 15px; fill: #0f172a; text-anchor: end; }
      
      .txt-id { font-family: 'Segoe UI', system-ui, -apple-system, sans-serif; font-size: 13.5px; font-weight: 750; fill: #0f172a; }
      .txt-sub { font-family: 'Consolas', 'Menlo', 'Monaco', monospace; font-size: 11.5px; fill: #334155; }
      .txt-val { font-family: 'Consolas', 'Menlo', 'Monaco', monospace; font-size: 10.5px; fill: #475569; }
      .txt-wire-tag { font-family: 'Consolas', 'Menlo', 'Monaco', monospace; font-size: 11px; font-weight: 600; }
      
      .txt-meta-lbl { font-family: 'Segoe UI', system-ui, -apple-system, sans-serif; font-size: 10px; text-transform: uppercase; font-weight: 700; fill: #64748b; letter-spacing: 0.5px; }
      .txt-meta-val { font-family: 'Segoe UI', system-ui, -apple-system, sans-serif; font-size: 13.5px; font-weight: 700; fill: #0f172a; }
      .txt-note { font-family: 'Consolas', 'Menlo', 'Monaco', monospace; font-size: 10.5px; fill: #1e293b; }
      .txt-alert { font-family: 'Consolas', 'Menlo', 'Monaco', monospace; font-size: 10.5px; font-weight: 700; fill: #b91c1c; }
    </style>

    <marker id="arr-rheo" markerWidth="8" markerHeight="8" refX="6" refY="4" orient="auto">
      <path d="M 1,1 L 7,4 L 1,7 Z" fill="#0f172a" />
    </marker>
  </defs>

  <!-- Background -->
  <rect x="0" y="0" width="1200" height="820" class="bg"/>

  <!-- Outer Drawing Border -->
  <rect x="14" y="14" width="1172" height="792" class="border-main"/>

  <!-- Header Strip -->
  <rect x="14" y="14" width="1172" height="42" class="header-bg"/>
  <text x="32" y="41" class="txt-hd">L&amp;R PRECISION CLEANING MACHINE — CONTROL UNIT — AS-BUILT 3-WIRE GROUNDED REWIRE (R-5)</text>
  <text x="1170" y="41" class="txt-hd-right">LR-ELEC-003 Rev A</text>

  <!-- ========================================================================= -->
  <!-- MAIN RAILS & NODES (N2 HOT & N1 NEUTRAL)                                 -->
  <!-- ========================================================================= -->

  <!-- N2 HOT RAIL -->
  <line x1="140" y1="120" x2="1030" y2="120" class="w-blk"/>
  <!-- N2 Label Badge -->
  <rect x="140" y="93" width="28" height="18" class="node-pill"/>
  <text x="154" y="106" class="node-pill-txt">N2</text>
  <text x="174" y="107" class="txt-id">HOT <tspan class="txt-sub">(Line, BLK)</tspan></text>
  <!-- N2 Wago Callout -->
  <rect x="260" y="94" width="70" height="16" class="wago-tag"/>
  <text x="295" y="106" class="wago-txt">WAGO 5p</text>

  <!-- N1 NEUTRAL RAIL -->
  <line x1="140" y1="560" x2="1030" y2="560" class="w-wht"/>
  <!-- N1 Label Badge -->
  <rect x="140" y="568" width="28" height="18" class="node-pill"/>
  <text x="154" y="581" class="node-pill-txt">N1</text>
  <text x="174" y="582" class="txt-id">NEUTRAL <tspan class="txt-sub">(WHT)</tspan></text>
  <!-- N1 Wago Callout -->
  <rect x="290" y="569" width="70" height="16" class="wago-tag"/>
  <text x="325" y="581" class="wago-txt">WAGO 3p</text>

  <!-- ========================================================================= -->
  <!-- SECTION 1: INLET (P1) & CHASSIS GROUND BOND (W-6)                         -->
  <!-- ========================================================================= -->
  
  <rect x="26" y="270" width="84" height="116" class="comp-body" fill="#ffffff" rx="2"/>
  <text x="68" y="292" class="txt-id" text-anchor="middle">P1</text>
  <text x="68" y="310" class="txt-sub" text-anchor="middle" font-weight="bold">CTL-008</text>
  <text x="68" y="328" class="txt-val" text-anchor="middle">3-wire</text>
  <text x="68" y="344" class="txt-val" text-anchor="middle">NEMA</text>
  <text x="68" y="358" class="txt-val" text-anchor="middle">5-15P</text>
  <circle cx="110" cy="295" r="3.5" class="node-dot"/>
  <circle cx="110" cy="330" r="3.5" class="node-dot"/>
  <circle cx="110" cy="365" r="3.5" class="node-dot"/>

  <!-- P1 Line (BLK) -> N2 -->
  <path d="M 110,295 L 150,295 L 150,120" class="w-blk"/>
  <circle cx="150" cy="120" r="4" class="node-dot"/>
  <text x="114" y="289" class="txt-wire-tag" fill="#0f172a">L (blk)</text>

  <!-- P1 Neutral (WHT) -> N1 -->
  <path d="M 110,330 L 130,330 L 130,560 L 140,560" class="w-wht"/>
  <circle cx="140" cy="560" r="4" class="node-dot"/>
  <text x="114" y="324" class="txt-wire-tag" fill="#475569">N (wht)</text>

  <!-- P1 Ground (GRN) -> Chassis Bond -->
  <path d="M 110,365 L 120,365 L 120,440" class="w-grn"/>
  <text x="114" y="359" class="txt-wire-tag" fill="#16a34a">G (grn)</text>
  <circle cx="120" cy="440" r="3" class="node-dot"/>

  <!-- Earth / Chassis Ground Symbol (W-6) -->
  <line x1="102" y1="440" x2="138" y2="440" class="w-grn" stroke-width="2.6"/>
  <line x1="109" y1="446" x2="131" y2="446" class="w-grn" stroke-width="2.6"/>
  <line x1="116" y1="452" x2="124" y2="452" class="w-grn" stroke-width="2.6"/>

  <text x="26" y="475" class="txt-wire-tag" fill="#16a34a" font-size="12px">W-6 CHASSIS BOND</text>
  <text x="26" y="491" class="txt-val">green ring lug + star washer</text>
  <text x="26" y="505" class="txt-val">to bare aluminium casting</text>

  <!-- ========================================================================= -->
  <!-- SECTION 2: HEATER & PILOT LAMP BRANCH (R1 || DS1 -> N3 -> S2 -> N1)       -->
  <!-- ========================================================================= -->

  <!-- R1 Feed & Tap from N2 -->
  <circle cx="340" cy="120" r="4" class="node-dot"/>
  <line x1="340" y1="120" x2="340" y2="160" class="w-blk"/>

  <!-- R1 Resistor Symbol (Zigzag) -->
  <!-- Start (340, 160) -> 6 peaks/troughs -> End (340, 240) -->
  <polyline points="340,160 340,165 354,171 326,183 354,195 326,207 354,219 326,231 340,237 340,240" class="comp-body"/>

  <!-- R1 Labels -->
  <text x="362" y="176" class="txt-id">R1 <tspan class="txt-sub">CTL-007</tspan></text>
  <text x="362" y="193" class="txt-meta-lbl" fill="#b91c1c">HEATER ELEMENT</text>
  <text x="362" y="209" class="txt-val">220 &#937; OHMITE</text>
  <text x="362" y="224" class="txt-val">P/N 33974 ~65W</text>

  <!-- R1 Lead to N3 -->
  <line x1="340" y1="240" x2="340" y2="280" class="w-red-dash"/>

  <!-- DS1 Feed & Tap from N2 -->
  <circle cx="490" cy="120" r="4" class="node-dot"/>
  <line x1="490" y1="120" x2="490" y2="175" class="w-blk"/>

  <!-- DS1 Lamp Symbol (Circle with internal X) -->
  <circle cx="490" cy="200" r="25" class="comp-body" fill="#ffffff"/>
  <line x1="472.3" y1="182.3" x2="507.7" y2="217.7" class="comp-body"/>
  <line x1="507.7" y1="182.3" x2="472.3" y2="217.7" class="comp-body"/>

  <!-- DS1 Labels -->
  <text x="524" y="188" class="txt-id">DS1 <tspan class="txt-sub">CTL-005</tspan></text>
  <text x="524" y="205" class="txt-meta-lbl">PILOT INDICATOR</text>
  <text x="524" y="221" class="txt-val">120V 6W (replaced)</text>

  <!-- DS1 Lead to N3 -->
  <line x1="490" y1="225" x2="490" y2="280" class="w-red-dash"/>

  <!-- N3 Bus (Heater / Lamp Common Return) -->
  <line x1="340" y1="280" x2="490" y2="280" class="w-red-dash"/>
  <circle cx="340" cy="280" r="4" class="node-dot"/>
  <circle cx="490" cy="280" r="4" class="node-dot"/>
  <circle cx="415" cy="280" r="4" class="node-dot"/>

  <!-- N3 Label Badge & Callouts -->
  <rect x="274" y="271" width="28" height="18" class="node-pill"/>
  <text x="288" y="284" class="node-pill-txt">N3</text>
  <text x="242" y="303" class="txt-wire-tag" fill="#dc2626">RED + band</text>
  <text x="242" y="316" class="txt-val">heater/lamp rtn</text>

  <rect x="380" y="264" width="70" height="16" class="wago-tag"/>
  <text x="415" y="276" class="wago-txt">WAGO 3p</text>

  <!-- Lead from N3 bus down to S2 Switch -->
  <line x1="415" y1="280" x2="415" y2="365" class="w-red-dash"/>

  <!-- S2 Heater Switch (SPST) -->
  <circle cx="415" cy="365" r="4" class="term-dot"/>
  <!-- Switch blade (open representation angled downwards) -->
  <line x1="415" y1="365" x2="437" y2="412" class="comp-body" stroke-width="2.5"/>
  <circle cx="415" cy="425" r="4" class="term-dot"/>

  <!-- S2 Labels -->
  <text x="444" y="380" class="txt-id">S2 <tspan class="txt-sub">CTL-004</tspan></text>
  <text x="444" y="397" class="txt-meta-lbl">HEATER SWITCH</text>
  <text x="444" y="413" class="txt-val">SPST replacement</text>

  <!-- Lead from S2 to N1 Neutral Rail -->
  <line x1="415" y1="425" x2="415" y2="560" class="w-wht"/>
  <circle cx="415" cy="560" r="4" class="node-dot"/>

  <!-- Sub-circuit Explanation Note Card -->
  <rect x="235" y="462" width="160" height="58" class="card-bg"/>
  <text x="242" y="480" class="txt-val" font-weight="bold">R1 || DS1 PARALLEL</text>
  <text x="242" y="495" class="txt-val">Connected across N2 &amp; N3.</text>
  <text x="242" y="508" class="txt-val">S2 switches return to N1.</text>

  <!-- ========================================================================= -->
  <!-- SECTION 3: MOTOR CONTROL BRANCH (S1 PLUNGER -> N4/N6 -> M1 -> N5 -> RV1) -->
  <!-- ========================================================================= -->

  <!-- Feed from N2 Hot Rail into S1 -->
  <circle cx="715" cy="120" r="4" class="node-dot"/>
  <line x1="715" y1="120" x2="715" y2="160" class="w-blk"/>

  <!-- S1 Plunger Switch Enclosure Box -->
  <rect x="615" y="160" width="200" height="135" class="comp-box" rx="4"/>
  <text x="625" y="180" class="txt-id">S1 <tspan class="txt-sub">CTL-003</tspan></text>
  <text x="625" y="196" class="txt-meta-lbl">PLUNGER TRANSFER SW</text>

  <!-- S1 Internal Schematics & Terminals -->
  <!-- Hot Common Terminals (d + b) -->
  <circle cx="715" cy="160" r="4" class="term-dot"/>
  <text x="715" y="152" class="txt-val" text-anchor="middle" font-weight="bold">d+b hot common</text>

  <!-- Switch Pole Arm (defaults to throw 'a' = OUT / FWD) -->
  <line x1="715" y1="160" x2="665" y2="255" class="comp-body" stroke-width="2.5"/>
  <!-- Throw 'a' -->
  <circle cx="665" cy="260" r="4" class="term-dot"/>
  <text x="665" y="278" class="txt-wire-tag" fill="#dc2626" text-anchor="middle">a</text>
  <!-- Throw 'c' -->
  <circle cx="765" cy="260" r="4" class="term-dot"/>
  <text x="765" y="278" class="txt-wire-tag" fill="#2563eb" text-anchor="middle">c</text>

  <!-- S1 Mechanical Operation Legend -->
  <text x="630" y="218" class="txt-val">OUT (rest) = a = FORWARD</text>
  <text x="630" y="232" class="txt-val">IN (press) = c = REVERSE</text>
  <text x="630" y="246" class="txt-val">Momentary; soft-start via RV1</text>

  <!-- Wiring from S1 to Motor Field Loom Junctions (N4 and N6) -->
  <!-- Path 'a' (RED) to N4 -->
  <line x1="665" y1="260" x2="665" y2="330" class="w-red"/>
  <circle cx="665" cy="330" r="3.5" class="node-dot"/>
  <line x1="665" y1="330" x2="685" y2="365" class="w-red"/>

  <!-- Path 'c' (BLU) to N6 -->
  <line x1="765" y1="260" x2="765" y2="330" class="w-blu"/>
  <circle cx="765" cy="330" r="3.5" class="node-dot"/>
  <line x1="765" y1="330" x2="745" y2="365" class="w-blu"/>

  <!-- N4 Badge & Annotation -->
  <rect x="600" y="321" width="28" height="18" class="node-pill"/>
  <text x="614" y="334" class="node-pill-txt">N4</text>
  <text x="590" y="349" class="txt-wire-tag" fill="#dc2626">RED (fwd)</text>
  <text x="590" y="362" class="txt-val">&#8594; loom wht</text>

  <!-- N6 Badge & Annotation -->
  <rect x="778" y="321" width="28" height="18" class="node-pill"/>
  <text x="792" y="334" class="node-pill-txt">N6</text>
  <text x="778" y="349" class="txt-wire-tag" fill="#2563eb">BLUE (rev)</text>
  <text x="778" y="362" class="txt-val">&#8594; loom blk</text>

  <!-- M1 Universal Motor Body -->
  <circle cx="715" cy="415" r="48" class="comp-body" fill="#ffffff" stroke-width="2.2"/>
  <!-- Field terminals on motor casing -->
  <circle cx="685" cy="365" r="3.5" class="node-dot"/>
  <circle cx="745" cy="365" r="3.5" class="node-dot"/>
  
  <text x="715" y="407" class="txt-id" text-anchor="middle" font-size="18px">M1</text>
  <text x="715" y="424" class="txt-meta-lbl" text-anchor="middle">UNIVERSAL</text>
  <text x="715" y="438" class="txt-val" text-anchor="middle">SERIES MOTOR</text>

  <!-- M1 Common Brush Lead (N5) -> Out to Rheostat RV1 -->
  <circle cx="763" cy="415" r="3.5" class="node-dot"/>
  <line x1="763" y1="415" x2="940" y2="415" class="w-yel"/>

  <!-- N5 Badge & Caution Callout -->
  <rect x="805" y="388" width="28" height="18" class="node-pill"/>
  <text x="819" y="401" class="node-pill-txt">N5</text>
  <text x="838" y="401" class="txt-wire-tag" fill="#d97706">common brush (YEL to loom grn)</text>
  <text x="805" y="430" class="txt-alert">&#9888; CAUTION: loom green = LIVE, band red</text>

  <!-- RV1 Rheostat (Speed Control + Integral OFF switch) -->
  <!-- Vertical wire down into resistor element -->
  <line x1="940" y1="415" x2="940" y2="445" class="w-yel"/>
  <circle cx="940" cy="445" r="3.5" class="node-dot"/>

  <!-- RV1 Zigzag Element -->
  <polyline points="940,445 940,450 955,456 925,468 955,480 925,492 955,504 925,516 940,522 940,530" class="comp-body"/>
  
  <!-- RV1 Wiper Arrow (diagonal wiper symbol entering resistor track) -->
  <line x1="985" y1="515" x2="935" y2="472" class="comp-body" stroke-width="2" marker-end="url(#arr-rheo)"/>

  <!-- RV1 CCW terminal connection to N1 Neutral Rail -->
  <circle cx="940" cy="530" r="3.5" class="node-dot"/>
  <line x1="940" y1="530" x2="940" y2="560" class="w-wht"/>
  <circle cx="940" cy="560" r="4" class="node-dot"/>

  <!-- RV1 Labels -->
  <text x="965" y="455" class="txt-id">RV1 <tspan class="txt-sub">CTL-001</tspan></text>
  <text x="965" y="471" class="txt-meta-lbl">SPEED CONTROL + OFF</text>
  <text x="965" y="487" class="txt-val">425 &#937; IRC Rheostat</text>
  <text x="965" y="501" class="txt-val">wiper = YEL, CCW = WHT</text>
  <text x="965" y="515" class="txt-val">full CCW = OFF (open)</text>

  <!-- ========================================================================= -->
  <!-- SECTION 4: COLOR KEY BOX                                                  -->
  <!-- ========================================================================= -->
  
  <rect x="1000" y="145" width="170" height="210" class="card-bg" stroke="#94a3b8"/>
  <text x="1012" y="167" class="txt-id" font-size="12.5px">WIRE COLOR KEY</text>
  <line x1="1012" y1="174" x2="1158" y2="174" class="border-sub"/>

  <!-- BLK -->
  <line x1="1012" y1="190" x2="1042" y2="190" class="w-blk"/>
  <text x="1050" y="194" class="txt-sub" font-weight="bold">BLK <tspan font-weight="normal">hot (N2)</tspan></text>

  <!-- WHT -->
  <line x1="1012" y1="210" x2="1042" y2="210" class="w-wht"/>
  <text x="1050" y="214" class="txt-sub" font-weight="bold">WHT <tspan font-weight="normal">neutral (N1)</tspan></text>

  <!-- GRN -->
  <line x1="1012" y1="230" x2="1042" y2="230" class="w-grn"/>
  <text x="1050" y="234" class="txt-sub" font-weight="bold" fill="#16a34a">GRN <tspan font-weight="normal">ground only</tspan></text>

  <!-- RED -->
  <line x1="1012" y1="250" x2="1042" y2="250" class="w-red"/>
  <text x="1050" y="254" class="txt-sub" font-weight="bold" fill="#dc2626">RED <tspan font-weight="normal">fwd (N4)</tspan></text>

  <!-- BLU -->
  <line x1="1012" y1="270" x2="1042" y2="270" class="w-blu"/>
  <text x="1050" y="274" class="txt-sub" font-weight="bold" fill="#2563eb">BLU <tspan font-weight="normal">rev (N6)</tspan></text>

  <!-- YEL -->
  <line x1="1012" y1="290" x2="1042" y2="290" class="w-yel"/>
  <text x="1050" y="294" class="txt-sub" font-weight="bold" fill="#d97706">YEL <tspan font-weight="normal">common (N5)</tspan></text>

  <!-- RED DASH -->
  <line x1="1012" y1="310" x2="1042" y2="310" class="w-red-dash"/>
  <text x="1050" y="314" class="txt-sub" font-weight="bold" fill="#dc2626">RED/band <tspan font-weight="normal">N3 rtn</tspan></text>

  <line x1="1012" y1="326" x2="1158" y2="326" class="border-sub"/>
  <text x="1012" y="339" class="txt-val">Junctions: Wago 221</text>
  <text x="1012" y="350" class="txt-val">lever nuts (serviceable)</text>

  <!-- ========================================================================= -->
  <!-- SECTION 5: LOWER BLOCK (NOTES & TITLE BLOCK)                              -->
  <!-- ========================================================================= -->

  <!-- Notes Container -->
  <rect x="26" y="605" width="708" height="190" class="card-bg" stroke="#0f172a" stroke-width="1.5"/>
  <text x="38" y="623" class="txt-id">ENGINEERING NOTES</text>

  <!-- Reproduction Caution Annotation (Preserved verbatim) -->
  <text x="38" y="640" class="txt-alert">REPRODUCTION DOCUMENT &#8212; Not an original L&amp;R Mfg. Co. technical publication. Reverse-engineered</text>
  <text x="38" y="654" class="txt-alert">from direct physical measurement of specimen S/N 13505. Curated by Hobbs R.E., 2026. Reference only.</text>

  <!-- Notes 1 to 6 (Preserved verbatim) -->
  <text x="38" y="674" class="txt-note">1. AS-BUILT corrected 3-wire GROUNDED rewire (R-5). Supersedes as-found LR-ELEC-002.</text>
  <text x="38" y="690" class="txt-note">2. MODERNIZED for safety + serviceability: 3-wire grounded cord + W-6 chassis bond (green ring lug);</text>
  <text x="56" y="704" class="txt-note">silicone 18 AWG 200C wire; Wago 221 lever-nut junctions (N2 5p, N1 3p, N3 3p; motor legs 2-wire).</text>
  <text x="56" y="718" class="txt-note">Deviations from original (solder/twist to Wago; 2-wire to 3-wire) documented per resto standard.</text>
  <text x="38" y="734" class="txt-note">3. Motor neck loom keeps LEGACY colors (grn=LIVE common, NOT ground) &#8212; loom green BANDED RED at N5.</text>
  <text x="38" y="750" class="txt-note">4. No master switch: N2 hot when plugged. RV1 OFF = motor off; sweep up = soft-start. S2 = heater/pilot.</text>
  <text x="38" y="766" class="txt-note">5. VERIFIED: Stage-0 cold-checks pass (gnd &lt;=0.2 ohm; no line-to-chassis short). First mains power-on OK:</text>
  <text x="56" y="780" class="txt-note">motor both directions, rheostat speed, heater ~160-200F, pilot lit. Operate: RV1 OFF before plug/unplug.</text>
  <text x="38" y="794" class="txt-note">6. Commutator sparks (normal brushed motor) = ignition source: use NON-FLAMMABLE solutions + ventilation.</text>

  <!-- Title Block Container -->
  <rect x="746" y="605" width="428" height="190" class="card-bg" stroke="#0f172a" stroke-width="1.5"/>
  
  <!-- Title Block Grid Lines -->
  <line x1="746" y1="648" x2="1174" y2="648" class="border-thin"/>
  <line x1="746" y1="698" x2="1174" y2="698" class="border-thin"/>
  <line x1="746" y1="748" x2="1174" y2="748" class="border-thin"/>
  <line x1="955" y1="648" x2="955" y2="795" class="border-thin"/>

  <!-- Title Header Banner -->
  <text x="960" y="632" class="txt-hd" text-anchor="middle" font-size="14px">L&amp;R PRECISION CLEANING MACHINE</text>

  <!-- Field: Model -->
  <text x="758" y="664" class="txt-meta-lbl">Product Model</text>
  <text x="758" y="684" class="txt-meta-val">Master</text>

  <!-- Field: Serial -->
  <text x="758" y="714" class="txt-meta-lbl">Product Serial</text>
  <text x="758" y="734" class="txt-meta-val">13505</text>

  <!-- Field: Manufacturer -->
  <text x="758" y="764" class="txt-meta-lbl">Manufacturer</text>
  <text x="758" y="784" class="txt-meta-val">L&amp;R MFG. CO.</text>

  <!-- Field: Date -->
  <text x="967" y="664" class="txt-meta-lbl">Date</text>
  <text x="967" y="684" class="txt-meta-val">June 12, 2026</text>

  <!-- Field: Engineer -->
  <text x="967" y="714" class="txt-meta-lbl">Engineer</text>
  <text x="967" y="734" class="txt-meta-val">Hobbs R.E.</text>

  <!-- Field: Drawing / Rev -->
  <text x="967" y="764" class="txt-meta-lbl">Drawing / Rev</text>
  <text x="967" y="779" class="txt-meta-val">LR-ELEC-003 / Rev A</text>
  <text x="967" y="791" class="txt-sub" font-size="9.5px">RELEASED &#8212; as-built + commissioned</text>

</svg>

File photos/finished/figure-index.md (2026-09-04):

# Finished-Machine Photos — Figure Index

> **REPRODUCTION DOCUMENT** — restoration record for specimen S/N 13505. Curated by Hobbs R.E., 2026. Final "beauty" photos of the completed, working restoration (studio gray background).

## Filed set — `photos/finished/`
| Target filename | Subject |
|---|---|
| `LR-13505-finished-01-full-3q.jpg` | Full machine, three-quarter view — motor head, chrome pillar, basket in heater well, solution jars in the bays |
| `LR-13505-finished-02-full-with-nameplate-inset.jpg` | Full machine with an inset close-up of the motor-head nameplate |
| `LR-13505-finished-03-motorhead-nameplate.jpg` | Close-up of the motor head / dome and the data nameplate |

## Nameplate data (from these photos)
- **L&R PRECISION CLEANING MACHINE** — Made by L&R MFG. CO., Arlington, N.J., U.S.A.
- **Serial No. 13505 · Model MASTER**
- **60 WATTS · AC & DC · 115 VOLTS · up to 75 cyc.**
- **U.S. Patents:** 1,872,812 · 1,817,266 · 1,907,366

## Status
- [x] **FILED 2026-09-03** — 3 finished-machine photos exported by operator and renamed to the convention above (from IMG_2718/2719/2720). These are the completed-restoration beauty shots.
- Good candidate for the **repo README hero image:** `LR-13505-finished-02-full-with-nameplate-inset.jpg`.

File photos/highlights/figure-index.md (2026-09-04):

# Restoration Highlights — Figure Index

> **REPRODUCTION DOCUMENT** — curated highlight photos from the restoration of specimen S/N 13505. Curated by Hobbs R.E., 2026. A representative selection; the full bench-photo record is retained off-repo.

A curated walk through the restoration, in order. Images downscaled for the repo (originals retained locally).

| File | Phase | Subject |
|---|---|---|
| `01-as-found-motor-head.jpg` | As-found | Original motor head with data nameplate, before teardown |
| `02-housing-stripped-bare.jpg` | Housing refinish | Both housing halves stripped to bare aluminum |
| `03-housing-wrinkle-finished.jpg` | Housing refinish | Housings after VHT black wrinkle finish |
| `04-armature-annotated.jpg` | Armature | Armature (rotor) with parts labeled — fan, core, commutator, collars |
| `05-bearing-wick-felt-kit.jpg` | Bearings & lube | Wool wick + felt-washer kit for the sleeve-bearing overhaul |
| `06-lower-housing-slinger-installed.jpg` | Bearings & lube | Lower housing with oil slinger pressed and bearing seated |
| `07-gasket-as-found-oxidized.jpg` | Gasket | Motor-cap gasket as-found — oxidized, patent 1,872,812 molded in |
| `08-gasket-restored-satin-black.jpg` | Gasket | Same gasket after cleaning + silicone conditioning |
| `09-basket-spindle-cleaned.jpg` | Basket | Mesh basket + drive spindle after ultrasonic cleaning |
| `10-base-casting-stripped.jpg` | Base refinish | Base casting stripped, three-quarter view (wells + pillar socket) |
| `11-control-components.jpg` | Control unit | All control-unit electrical components laid out |
| `12-heater-resistor-ohmite.jpg` | Control unit | Heater dropping resistor R1 — Ohmite stamp (P/N 33974) |
| `13-rheostat-425ohm.jpg` | Control unit | Speed-control rheostat RV1 (~425 Ω) |
| `14-plunger-switch-typeplate.jpg` | Control unit | Plunger transfer switch S1 — Arrow H&H type plate |
| `15-rheostat-knob-cast-face.jpg` | Controls | Cast rheostat face — "L&R MASTER" relief lettering + ON/OFF arc |
| `16-stator-field-topology.jpg` | Motor electrical | Stator field-coil topology, annotated (coil/pole/lead identification) |
| `17-stator-rebuilt-leads.jpg` | Motor electrical | Stator with rebuilt leads + anchored entry sheath (post field-failure repair) |
| `18-motor-bench-test.jpg` | Commissioning | Motor bench test on the Rigol supply (direction + speed verification) |

*See also `photos/finished/` for the completed-machine beauty shots.*

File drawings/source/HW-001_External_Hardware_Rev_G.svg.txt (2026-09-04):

<svg xmlns="http://www.w3.org/2000/svg" viewBox="0 0 1200 800" width="100%" height="100%">
    <defs>
        <style>
            .header-text { font-family: sans-serif; font-weight: bold; font-size: 16px; fill: #111; text-anchor: middle; letter-spacing: 1px; }
            .label-text { font-family: sans-serif; font-weight: bold; font-size: 10px; fill: #333; }
            .value-text { font-family: monospace; font-size: 12px; fill: #111; }
            .notes-text { font-family: sans-serif; font-size: 10px; fill: #111; }
            .grid-label { font-family: sans-serif; font-weight: bold; font-size: 10px; fill: #666; text-anchor: middle; }
            .disclaimer-text { font-family: sans-serif; font-style: italic; font-size: 9px; fill: #666; text-anchor: middle; }
        </style>
        
        <pattern id="threadHatch" width="4" height="20" patternUnits="userSpaceOnUse">
            <line x1="0" y1="5" x2="4" y2="0" stroke="#475569" stroke-width="1" />
            <line x1="0" y1="15" x2="4" y2="10" stroke="#475569" stroke-width="1" />
        </pattern>

        <pattern id="denseHatch" width="4" height="4" patternUnits="userSpaceOnUse" patternTransform="rotate(45)">
            <line x1="0" y1="0" x2="0" y2="4" stroke="#64748b" stroke-width="1" />
        </pattern>

        <linearGradient id="brassGradient" x1="0%" y1="0%" x2="0%" y2="100%">
            <stop offset="0%" stop-color="#fef08a" />
            <stop offset="30%" stop-color="#eab308" />
            <stop offset="70%" stop-color="#ca8a04" />
            <stop offset="100%" stop-color="#854d0e" />
        </linearGradient>
        
        <marker id="arr-l" viewBox="0 0 10 10" refX="0" refY="5" markerWidth="6" markerHeight="6" orient="auto-start-reverse">
            <path d="M 10 0 L 0 5 L 10 10 z" fill="#0369a1"/>
        </marker>
        <marker id="arr-r" viewBox="0 0 10 10" refX="10" refY="5" markerWidth="6" markerHeight="6" orient="auto">
            <path d="M 0 0 L 10 5 L 0 10 z" fill="#0369a1"/>
        </marker>
    </defs>

    <rect width="1200" height="800" fill="#f8f9fa" />

    <rect x="15" y="15" width="1170" height="770" fill="none" stroke="#111" stroke-width="1" />
    <rect x="35" y="35" width="1130" height="730" fill="none" stroke="#111" stroke-width="2" />

    <line x1="320" y1="15" x2="320" y2="35" stroke="#111" stroke-width="1" />
    <line x1="600" y1="15" x2="600" y2="35" stroke="#111" stroke-width="1" />
    <line x1="880" y1="15" x2="880" y2="35" stroke="#111" stroke-width="1" />
    <text x="177" y="28" class="grid-label">A</text>
    <text x="460" y="28" class="grid-label">B</text>
    <text x="740" y="28" class="grid-label">C</text>
    <text x="1020" y="28" class="grid-label">D</text>

    <line x1="15" y1="152" x2="35" y2="152" stroke="#111" stroke-width="1" />
    <line x1="15" y1="267" x2="35" y2="267" stroke="#111" stroke-width="1" />
    <line x1="15" y1="382" x2="35" y2="382" stroke="#111" stroke-width="1" />
    <line x1="15" y1="497" x2="35" y2="497" stroke="#111" stroke-width="1" />
    <line x1="15" y1="620" x2="35" y2="620" stroke="#111" stroke-width="1" />
    <text x="25" y="100" class="grid-label">1</text>
    <text x="25" y="215" class="grid-label">2</text>
    <text x="25" y="330" class="grid-label">3</text>
    <text x="25" y="445" class="grid-label">4</text>
    <text x="25" y="560" class="grid-label">5</text>

    <line x1="1165" y1="152" x2="1185" y2="152" stroke="#111" stroke-width="1" />
    <line x1="1165" y1="267" x2="1185" y2="267" stroke="#111" stroke-width="1" />
    <line x1="1165" y1="382" x2="1185" y2="382" stroke="#111" stroke-width="1" />
    <line x1="1165" y1="497" x2="1185" y2="497" stroke="#111" stroke-width="1" />
    <line x1="1165" y1="620" x2="1185" y2="620" stroke="#111" stroke-width="1" />

    <line x1="320" y1="765" x2="320" y2="785" stroke="#111" stroke-width="1" />
    <line x1="600" y1="765" x2="600" y2="785" stroke="#111" stroke-width="1" />
    <line x1="880" y1="765" x2="880" y2="785" stroke="#111" stroke-width="1" />

    <line x1="600" y1="35" x2="600" y2="620" stroke="#ccc" stroke-width="1" stroke-dasharray="15,5,5,5" />
    
    <line x1="35" y1="152" x2="1165" y2="152" stroke="#ccc" stroke-width="1" stroke-dasharray="15,5,5,5" />
    <line x1="35" y1="267" x2="1165" y2="267" stroke="#ccc" stroke-width="1" stroke-dasharray="15,5,5,5" />
    <line x1="35" y1="382" x2="1165" y2="382" stroke="#ccc" stroke-width="1" stroke-dasharray="15,5,5,5" />
    <line x1="35" y1="497" x2="1165" y2="497" stroke="#ccc" stroke-width="1" stroke-dasharray="15,5,5,5" />

    <g id="part-flg-002" transform="translate(60, 40) scale(0.80)">
        <text x="10" y="20" fill="#0f172a" font-family="sans-serif" font-size="12" font-weight="bold">ITEM 1: FLG-002 HOUSING MAIN TIE-BOLT (2X TOTAL)</text>
        <text x="10" y="35" fill="#c2410c" font-family="sans-serif" font-size="10" font-weight="bold">NOTE: FLG-002 also passes through the two PLT-004 standoff tubes to clamp the platform deck.</text>
        
        <line x1="20" y1="100" x2="310" y2="100" stroke="#94a3b8" stroke-width="1" stroke-dasharray="10,4,2,4" />
        
        <rect x="30" y="75" width="35" height="50" rx="3" fill="#f8fafc" stroke="#0f172a" stroke-width="2" />
        <rect x="30" y="94" width="12" height="12" fill="#475569" stroke="#0f172a" stroke-width="1" />
        
        <rect x="65" y="86" width="140" height="28" fill="#f1f5f9" stroke="#0f172a" stroke-width="1.5" />
        <rect x="205" y="86" width="75" height="28" fill="url(#threadHatch)" stroke="#0f172a" stroke-width="1.5" />
        <line x1="280" y1="89" x2="280" y2="111" stroke="#0f172a" stroke-width="1.5" />

        <g stroke="#0369a1" stroke-width="1" fill="#0369a1" font-family="monospace" font-size="11">
            <line x1="30" y1="70" x2="30" y2="55" stroke="#94a3b8" stroke-width="0.75"/>
            <line x1="65" y1="70" x2="65" y2="55" stroke="#94a3b8" stroke-width="0.75"/>
            <line x1="40" y1="60" x2="55" y2="60" marker-start="url(#arr-l)" marker-end="url(#arr-r)"/>
            <text x="47.5" y="52" text-anchor="middle" font-weight="bold">0.350"</text>

            <line x1="65" y1="120" x2="65" y2="145" stroke="#94a3b8" stroke-width="0.75"/>
            <line x1="280" y1="120" x2="280" y2="145" stroke="#94a3b8" stroke-width="0.75"/>
            <line x1="75" y1="135" x2="270" y2="135" marker-start="url(#arr-l)" marker-end="url(#arr-r)"/>
            <text x="172.5" y="129" text-anchor="middle" font-weight="bold">SHANK OAL: 3.090" (CONFIRMED)</text>
        </g>
    </g>

    <g id="part-lh-006-tube" transform="translate(620, 40) scale(0.80)">
        <text x="10" y="20" fill="#0f172a" font-family="sans-serif" font-size="12" font-weight="bold">ITEM 2: LH-006 PROTRUDING BRASS OIL TUBE (1X TOTAL)</text>
        
        <line x1="30" y1="95" x2="320" y2="95" stroke="#94a3b8" stroke-width="1" stroke-dasharray="10,4,2,4" />
        
        <path d="M 40,65 L 75,65 L 75,125 L 40,125" fill="#f1f5f9" stroke="#94a3b8" stroke-width="1" stroke-dasharray="2,2"/>
        <text x="58" y="115" fill="#94a3b8" font-family="sans-serif" font-size="9" text-anchor="middle">LH-005 BOSS</text>

        <rect x="55" y="79" width="20" height="32" fill="#ca8a04" stroke="#0f172a" stroke-width="1.5" opacity="0.5" />
        <rect x="75" y="79" width="165" height="32" fill="url(#brassGradient)" stroke="#0f172a" stroke-width="2" />
        
        <path d="M 240,76 L 246,76 L 246,114 L 240,114 Z" fill="#ca8a04" stroke="#0f172a" stroke-width="1.5" />
        <ellipse cx="246" cy="95" rx="2" ry="16" fill="#451a03" />

        <g stroke="#0369a1" stroke-width="1" fill="#0369a1" font-family="monospace" font-size="11">
            <line x1="246" y1="76" x2="275" y2="76" stroke="#94a3b8" stroke-width="0.75"/>
            <line x1="246" y1="114" x2="275" y2="114" stroke="#94a3b8" stroke-width="0.75"/>
            <line x1="270" y1="86" x2="270" y2="104" marker-start="url(#arr-r)" marker-end="url(#arr-l)"/>
            <text x="282" y="99" text-anchor="start" font-weight="bold">OD Ø0.293" (CONF)</text>

            <line x1="75" y1="79" x2="75" y2="45" stroke="#94a3b8" stroke-width="0.75"/>
            <line x1="246" y1="76" x2="246" y2="45" stroke="#94a3b8" stroke-width="0.75"/>
            <line x1="85" y1="50" x2="236" y2="50" marker-start="url(#arr-l)" marker-end="url(#arr-r)"/>
            <text x="160" y="44" text-anchor="middle" font-weight="bold">PROTRUSION LEN: 1.000" (CONFIRMED)</text>
        </g>
    </g>

    <g id="part-uh-004" transform="translate(60, 155) scale(0.80)">
        <text x="10" y="20" fill="#0f172a" font-family="sans-serif" font-size="12" font-weight="bold">ITEM 3: UH-004 INSULATED BRUSH CAP PLUG (2X TOTAL)</text>
        
        <g transform="translate(80, 85)">
            <circle cx="0" cy="0" r="45" fill="#f8fafc" stroke="#0f172a" stroke-width="2" />
            <circle cx="0" cy="0" r="38" fill="none" stroke="#475569" stroke-width="1" stroke-dasharray="2,2" />
            <rect x="-30" y="-5" width="60" height="10" fill="#334155" stroke="#0f172a" stroke-width="1" />
            <text x="0" y="58" fill="#475569" font-family="sans-serif" font-size="10" font-weight="bold" text-anchor="middle">PLAN VIEW FACE</text>
        </g>

        <g transform="translate(240, 85)">
            <path d="M -45,-25 L 45,-25 L 45,-10 L 35,20 L -35,20 L -45,-10 Z" fill="#f1f5f9" stroke="#0f172a" stroke-width="2" />
            <rect x="-30" y="-25" width="60" height="10" fill="none" stroke="#475569" stroke-width="1" stroke-dasharray="3,3" />
            <text x="0" y="38" fill="#475569" font-family="sans-serif" font-size="10" font-weight="bold" text-anchor="middle">SIDE PROFILE</text>
        </g>

        <g stroke="#0369a1" stroke-width="1" fill="#0369a1" font-family="monospace" font-size="11">
            <line x1="35" y1="85" x2="35" y2="155" stroke="#94a3b8" stroke-width="0.75"/>
            <line x1="125" y1="85" x2="125" y2="155" stroke="#94a3b8" stroke-width="0.75"/>
            <line x1="45" y1="147" x2="115" y2="147" marker-start="url(#arr-l)" marker-end="url(#arr-r)"/>
            <text x="80" y="141" text-anchor="middle" font-weight="bold">OD Ø0.560" (SYN)</text>
        </g>
    </g>

    <g id="part-uh-005" transform="translate(620, 155) scale(0.80)">
        <text x="10" y="20" fill="#0f172a" font-family="sans-serif" font-size="12" font-weight="bold">ITEM 4: UH-005 LOCKING SET-SCREW (2X TOTAL)</text>
        
        <line x1="40" y1="90" x2="240" y2="90" stroke="#94a3b8" stroke-width="1" stroke-dasharray="10,4,2,4" />
        
        <rect x="70" y="70" width="85" height="40" fill="url(#threadHatch)" stroke="#0f172a" stroke-width="2" />
        <path d="M 70,80 L 85,80 L 85,100 L 70,100 Z" fill="#475569" stroke="#0f172a" stroke-width="1.2" />
        <rect x="155" y="75" width="10" height="30" fill="#cbd5e1" stroke="#0f172a" stroke-width="1.5" />

        <g stroke="#0369a1" stroke-width="1" fill="#0369a1" font-family="monospace" font-size="11">
            <line x1="70" y1="65" x2="70" y2="40" stroke="#94a3b8" stroke-width="0.75"/>
            <line x1="165" y1="65" x2="165" y2="40" stroke="#94a3b8" stroke-width="0.75"/>
            <line x1="80" y1="47" x2="155" y2="47" marker-start="url(#arr-l)" marker-end="url(#arr-r)"/>
            <text x="117.5" y="40" text-anchor="middle" font-weight="bold">LEN: 0.312" (5/16)</text>
            
            <text x="117.5" y="130" text-anchor="middle" font-weight="bold" fill="#0369a1">THREAD: M4 / #8-32 EQUIV.</text>
        </g>
    </g>

    <g id="part-plt-004" transform="translate(60, 270) scale(0.80)">
        <text x="10" y="20" fill="#0f172a" font-family="sans-serif" font-size="12" font-weight="bold">ITEM 5: PLT-004 MOUNT STANDOFF TUBE (2X TOTAL)</text>
        <text x="10" y="35" fill="#475569" font-family="sans-serif" font-size="10">NOTE: FLG-002 housing bolts pass THROUGH these tubes; they set platform-deck standoff.</text>
        
        <line x1="30" y1="90" x2="280" y2="90" stroke="#94a3b8" stroke-width="1" stroke-dasharray="10,4,2,4" />
        
        <rect x="60" y="70" width="160" height="40" fill="url(#denseHatch)" stroke="#0f172a" stroke-width="1.5" />
        <rect x="60" y="80" width="160" height="20" fill="#ffffff" stroke="#0f172a" stroke-width="1.5" />
        <line x1="60" y1="90" x2="220" y2="90" stroke="#0f172a" stroke-width="1" stroke-dasharray="8,4"/>

        <g stroke="#0369a1" stroke-width="1" fill="#0369a1" font-family="monospace" font-size="11">
            <line x1="60" y1="65" x2="60" y2="45" stroke="#94a3b8" stroke-width="0.75"/>
            <line x1="220" y1="65" x2="220" y2="45" stroke="#94a3b8" stroke-width="0.75"/>
            <line x1="70" y1="52" x2="210" y2="52" marker-start="url(#arr-l)" marker-end="url(#arr-r)"/>
            <text x="140" y="45" text-anchor="middle" font-weight="bold">LEN: 0.6990" (CONFIRMED)</text>

            <line x1="220" y1="70" x2="250" y2="70" stroke="#94a3b8" stroke-width="0.75"/>
            <line x1="220" y1="110" x2="250" y2="110" stroke="#94a3b8" stroke-width="0.75"/>
            <line x1="240" y1="80" x2="240" y2="100" marker-start="url(#arr-r)" marker-end="url(#arr-l)"/>
            <text x="250" y="95" text-anchor="start" font-weight="bold">OD 0.3765" (CONF)</text>

            <line x1="140" y1="95" x2="140" y2="125" stroke="#94a3b8" stroke-width="0.75"/>
            <text x="140" y="135" text-anchor="middle" font-weight="bold">BORE ID: 0.2020" (CONFIRMED) | WALL ~0.087" (SYN)</text>
        </g>
    </g>

    <g id="part-spn-005" transform="translate(620, 270) scale(0.80)">
        <text x="10" y="20" fill="#0f172a" font-family="sans-serif" font-size="12" font-weight="bold">ITEM 6: SPN-005 SPINDLE SET SCREW (1X TOTAL)</text>
        <text x="10" y="35" fill="#475569" font-family="sans-serif" font-size="10">NOTE: Locks armature lower journal (SHF-003) inside the basket drive spindle (SPN-002).</text>
        
        <line x1="40" y1="90" x2="200" y2="90" stroke="#94a3b8" stroke-width="1" stroke-dasharray="10,4,2,4" />
        
        <rect x="70" y="75" width="40" height="30" fill="url(#threadHatch)" stroke="#0f172a" stroke-width="2" />
        <path d="M 70,80 L 60,80 L 60,100 L 70,100 Z" fill="#475569" stroke="#0f172a" stroke-width="1.2" />
        <rect x="110" y="75" width="8" height="30" fill="#cbd5e1" stroke="#0f172a" stroke-width="1.5" />
        <rect x="114" y="83" width="4" height="14" fill="#0f172a" />

        <g stroke="#0369a1" stroke-width="1" fill="#0369a1" font-family="monospace" font-size="11">
            <line x1="60" y1="70" x2="60" y2="50" stroke="#94a3b8" stroke-width="0.75"/>
            <line x1="118" y1="70" x2="118" y2="50" stroke="#94a3b8" stroke-width="0.75"/>
            <line x1="70" y1="57" x2="108" y2="57" marker-start="url(#arr-l)" marker-end="url(#arr-r)"/>
            <text x="89" y="50" text-anchor="middle" font-weight="bold">LEN: 0.185" (CONF)</text>

            <text x="100" y="125" text-anchor="middle" font-weight="bold" fill="#0369a1">THREAD: 1/4-20 (RH) | DRIVE: SLOTTED</text>
        </g>
    </g>

    <g id="part-spn-006" transform="translate(60, 385) scale(0.80)">
        <text x="10" y="20" fill="#0f172a" font-family="sans-serif" font-size="12" font-weight="bold">ITEM 7: SPN-006 BASKET RETENTION SPRING (1X TOTAL)</text>
        <text x="10" y="35" fill="#475569" font-family="sans-serif" font-size="10">NOTE: 3-prong steel spring at the spindle impeller hub; basket secures against it.</text>
        
        <line x1="30" y1="85" x2="280" y2="85" stroke="#94a3b8" stroke-width="1" stroke-dasharray="10,4,2,4" />
        
        <g transform="translate(120, 85)">
            <g transform="rotate(0)"><rect x="-5" y="-40" width="10" height="40" fill="#94a3b8" stroke="#0f172a" stroke-width="1.5"/></g>
            <g transform="rotate(120)"><rect x="-5" y="-40" width="10" height="40" fill="#94a3b8" stroke="#0f172a" stroke-width="1.5"/></g>
            <g transform="rotate(240)"><rect x="-5" y="-40" width="10" height="40" fill="#94a3b8" stroke="#0f172a" stroke-width="1.5"/></g>
            <circle cx="0" cy="0" r="12" fill="#cbd5e1" stroke="#0f172a" stroke-width="1.5"/>
            <circle cx="0" cy="0" r="4" fill="#ffffff" stroke="#0f172a" stroke-width="1"/>
        </g>

        <g stroke="#0369a1" stroke-width="1" fill="#0369a1" font-family="monospace" font-size="11">
            <line x1="80" y1="75" x2="80" y2="50" stroke="#94a3b8" stroke-width="0.75"/>
            <line x1="160" y1="75" x2="160" y2="50" stroke="#94a3b8" stroke-width="0.75"/>
            <line x1="90" y1="57" x2="150" y2="57" marker-start="url(#arr-l)" marker-end="url(#arr-r)"/>
            <text x="120" y="50" text-anchor="middle" font-weight="bold">SPREAD: 1.91" (CONF)</text>

            <text x="120" y="140" text-anchor="middle" font-weight="bold">LEGS: 0.24"H x 0.95"L x 0.0265" THICK (CONF)</text>
        </g>
    </g>

    <g id="part-spn-007" transform="translate(620, 385) scale(0.80)">
        <text x="10" y="20" fill="#0f172a" font-family="sans-serif" font-size="12" font-weight="bold">ITEM 8: SPN-007 SPRING RETAINING SCREW (1X TOTAL)</text>
        <text x="10" y="35" fill="#475569" font-family="sans-serif" font-size="10">NOTE: Brass slotted dome head screw; fastens SPN-006 to the spindle hub.</text>
        
        <line x1="40" y1="85" x2="240" y2="85" stroke="#94a3b8" stroke-width="1" stroke-dasharray="10,4,2,4" />
        
        <path d="M 70,70 C 50,70 50,100 70,100 Z" fill="url(#brassGradient)" stroke="#0f172a" stroke-width="2" />
        <rect x="52" y="83" width="4" height="4" fill="#451a03" />
        <rect x="70" y="77" width="60" height="16" fill="url(#threadHatch)" stroke="#0f172a" stroke-width="1.5" />

        <g stroke="#0369a1" stroke-width="1" fill="#0369a1" font-family="monospace" font-size="11">
            <line x1="60" y1="65" x2="60" y2="50" stroke="#94a3b8" stroke-width="0.75"/>
            <line x1="130" y1="73" x2="130" y2="50" stroke="#94a3b8" stroke-width="0.75"/>
            <line x1="70" y1="57" x2="120" y2="57" marker-start="url(#arr-l)" marker-end="url(#arr-r)"/>
            <text x="95" y="50" text-anchor="middle" font-weight="bold">LEN: 0.465" (CONF)</text>

            <text x="110" y="125" text-anchor="middle" font-weight="bold">HEAD: Ø0.265" | THREAD: #6-32 (CONF)</text>
        </g>
    </g>

    <g id="part-plt-005" transform="translate(60, 500) scale(0.80)">
        <text x="10" y="20" fill="#0f172a" font-family="sans-serif" font-size="12" font-weight="bold">ITEM 9: PLT-005 GASKET DECK FASTENER (4X TOTAL)</text>
        <text x="10" y="35" fill="#475569" font-family="sans-serif" font-size="10">NOTE: Original = Rivet. Restoration = stainless M4-0.7 x 10mm flat-head Phillips screw + hex nut.</text>
        <text x="10" y="47" fill="#475569" font-family="sans-serif" font-size="10">NOTE: Restoration specifically reuses the original PLT-006 washers.</text>

        <line x1="40" y1="90" x2="240" y2="90" stroke="#94a3b8" stroke-width="1" stroke-dasharray="10,4,2,4" />
        
        <path d="M 70,80 C 55,80 55,100 70,100 Z" fill="#cbd5e1" stroke="#0f172a" stroke-width="1.5" />
        <rect x="70" y="86" width="60" height="8" fill="#e2e8f0" stroke="#0f172a" stroke-width="1.5" />

        <g stroke="#0369a1" stroke-width="1" fill="#0369a1" font-family="monospace" font-size="11">
            <text x="110" y="125" text-anchor="middle" font-weight="bold">ORIGINAL RIVET (DESIGN OF RECORD)</text>
        </g>
    </g>

    <g id="part-plt-006" transform="translate(620, 500) scale(0.80)">
        <text x="10" y="20" fill="#0f172a" font-family="sans-serif" font-size="12" font-weight="bold">ITEM 10: PLT-006 GASKET DECK WASHER (4X TOTAL)</text>
        <text x="10" y="35" fill="#475569" font-family="sans-serif" font-size="10">NOTE: Original washer. Retained for use with restoration M4 hardware.</text>
        
        <line x1="40" y1="90" x2="300" y2="90" stroke="#94a3b8" stroke-width="1" stroke-dasharray="10,4,2,4" />

        <circle cx="100" cy="90" r="28" fill="#e2e8f0" stroke="#0f172a" stroke-width="1.5" />
        <circle cx="100" cy="90" r="10" fill="#f8fafc" stroke="#0f172a" stroke-width="1.5" />
        
        <rect x="220" y="62" width="6" height="56" fill="#e2e8f0" stroke="#0f172a" stroke-width="1.5" />
        <line x1="223" y1="60" x2="223" y2="120" stroke="#0f172a" stroke-width="1" stroke-dasharray="4,2"/>

        <g stroke="#0369a1" stroke-width="1" fill="#0369a1" font-family="monospace" font-size="11">
            <text x="100" y="140" text-anchor="middle" font-weight="bold">OD Ø0.4385" (CONF)</text>
            <text x="100" y="152" text-anchor="middle" font-weight="bold">ID Ø0.1570" (CONF)</text>
            <text x="223" y="140" text-anchor="middle" font-weight="bold">THICK: 0.0415" (CONF)</text>
        </g>
    </g>

    <line x1="35" y1="620" x2="1165" y2="620" stroke="#111" stroke-width="2" />
    
    <rect x="45" y="630" width="530" height="135" fill="#fff" stroke="#111" stroke-width="2" />
    <text x="55" y="645" class="label-text">NOTES &amp; SPECIFICATIONS:</text>
    <text x="55" y="660" class="notes-text">1. SCOPE: Ancillary hardware schedule mapping structural fasteners, plugs, and spindle hardware.</text>
    <text x="55" y="672" class="notes-text">2. TIE-BOLTS (FLG-002): Pass through stator yoke to clamp upper and lower housings.</text>
    <text x="55" y="684" class="notes-text">3. OIL TUBE (LH-006): Brass tube pressed into lower casting; houses lubricating wick.</text>
    <text x="55" y="696" class="notes-text">4. BRUSH CAPS (UH-004) / SET SCREWS (UH-005): Plugs and retainers for carbon motor brushes.</text>
    <text x="55" y="708" class="notes-text">5. STANDOFFS (PLT-004): Flange bolts route inside these to structure the platform deck assembly.</text>
    <text x="55" y="720" class="notes-text">6. SPINDLE HARDWARE: SPN-005 (set screw) + SPN-006 (3-prong spring) + SPN-007 (brass retention screw).</text>
    <text x="55" y="732" class="notes-text">7. METROLOGY: Dimensions marked (EST.) or (SYN) pending direct bench confirmation.</text>
    <text x="55" y="744" class="notes-text">8. DECK FASTENERS (PLT-005): Original rivets drilled out; replaced with M4 hardware.</text>

    <rect x="585" y="630" width="570" height="135" fill="#fff" stroke="#111" stroke-width="2" />
    
    <line x1="585" y1="660" x2="1155" y2="660" stroke="#111" stroke-width="2" />
    <line x1="585" y1="710" x2="1155" y2="710" stroke="#111" stroke-width="1" />
    
    <line x1="755" y1="660" x2="755" y2="765" stroke="#111" stroke-width="1" />
    <line x1="965" y1="660" x2="965" y2="765" stroke="#111" stroke-width="1" />
    <line x1="1065" y1="710" x2="1065" y2="765" stroke="#111" stroke-width="1" />

    <text x="870" y="650" class="header-text">L&amp;R PRECISION CLEANING MACHINE — MASTER</text>
    
    <text x="595" y="680" class="label-text">MANUFACTURER:</text>
    <text x="595" y="700" class="value-text" font-weight="bold">L&amp;R MFG. CO.</text>
    
    <text x="765" y="680" class="label-text">DRAWING TITLE:</text>
    <text x="765" y="700" class="value-text" font-weight="bold" font-size="10px" textLength="185" lengthAdjust="spacingAndGlyphs">EXTERNAL HARDWARE SCHEDULE (REV G)</text>
    
    <text x="975" y="680" class="label-text">PART NUMBER / ID:</text>
    <text x="975" y="700" class="value-text" font-weight="bold" fill="#ff3333">HW-001</text>

    <text x="595" y="725" class="label-text">ENGINEER:</text>
    <text x="595" y="745" class="value-text">Hobbs R.E.</text>
    
    <text x="765" y="725" class="label-text">METADATA CONTROL:</text>
    <text x="765" y="740" class="value-text" font-size="10px">SCALE: NOT TO SCALE</text>
    <text x="765" y="753" class="value-text" font-size="10px">SERIAL NUMBER: S/N 13505</text>
    
    <text x="975" y="725" class="label-text">DATE:</text>
    <text x="975" y="745" class="value-text">June 12, 2026</text>
    
    <text x="1075" y="725" class="label-text">STATUS:</text>
    <text x="1075" y="745" class="value-text" font-weight="bold" fill="#228b22">RELEASED</text>

    <text x="600" y="780" class="disclaimer-text">REPRODUCTION DOCUMENT — Not an original L&amp;R Mfg. Co. technical publication. Reverse-engineered from direct physical measurement of specimen S/N 13505. Curated by Hobbs R.E., 2026. For restoration reference only.</text>
</svg>

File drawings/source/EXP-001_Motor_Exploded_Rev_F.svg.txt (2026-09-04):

<svg xmlns="http://www.w3.org/2000/svg" viewBox="0 0 1200 2200" width="100%" height="100%">
    <defs>
        <style>
            .header-text { font-family: sans-serif; font-weight: bold; font-size: 16px; fill: #111; text-anchor: middle; letter-spacing: 1px; }
            .label-text { font-family: sans-serif; font-weight: bold; font-size: 11px; fill: #111; }
            .value-text { font-family: monospace; font-size: 12px; fill: #111; }
            .grid-label { font-family: sans-serif; font-weight: bold; font-size: 10px; fill: #666; text-anchor: middle; }
            .disclaimer-text { font-family: sans-serif; font-style: italic; font-size: 9px; fill: #666; text-anchor: middle; }
            
            .outline { stroke: #000; stroke-width: 2; fill: none; stroke-linecap: round; stroke-linejoin: round; }
            .fill-alum { fill: #e2e8f0; }
            .fill-iron { fill: #64748b; }
            .fill-copper { fill: #b45309; }
            .fill-comm { fill: #ea580c; }
            .fill-bronze { fill: #d97706; opacity: 0.8; }
            .fill-brass { fill: #facc15; }
            .fill-rubber { fill: #333333; }
            .fill-phenolic { fill: #78350f; opacity: 0.8; }
            
            .centerline-main { stroke: #0369a1; stroke-width: 1.5; stroke-dasharray: 20, 5, 5, 5; fill: none; }
            .centerline-bolt { stroke: #64748b; stroke-width: 1; stroke-dasharray: 10, 4, 2, 4; fill: none; }
            .leader { stroke: #334155; stroke-width: 1.5; fill: none; }
        </style>

        <pattern id="hatch-iron" width="8" height="8" patternUnits="userSpaceOnUse" patternTransform="rotate(45)">
            <line x1="0" y1="0" x2="0" y2="8" stroke="#334155" stroke-width="1.5" />
        </pattern>
        <pattern id="hatch-copper" width="6" height="6" patternUnits="userSpaceOnUse" patternTransform="rotate(-30)">
            <line x1="0" y1="0" x2="0" y2="6" stroke="#78350f" stroke-width="1" opacity="0.6" />
        </pattern>
        <pattern id="hatch-bronze" width="6" height="6" patternUnits="userSpaceOnUse" patternTransform="rotate(45)">
            <line x1="0" y1="0" x2="0" y2="6" stroke="#92400e" stroke-width="1" />
            <line x1="0" y1="0" x2="6" y2="0" stroke="#92400e" stroke-width="1" />
        </pattern>
        <pattern id="wire-mesh" width="6" height="6" patternUnits="userSpaceOnUse">
            <path d="M 0 0 L 6 6 M 6 0 L 0 6" stroke="#666" stroke-width="0.6"/>
            <path d="M 0 3 L 6 3 M 3 0 L 3 6" stroke="#888" stroke-width="0.3"/>
        </pattern>

        <marker id="dot" viewBox="0 0 10 10" refX="5" refY="5" markerWidth="5" markerHeight="5">
            <circle cx="5" cy="5" r="4" fill="#334155" />
        </marker>
    </defs>

    <rect width="1200" height="2200" fill="#f8f9fa" />

    <rect x="20" y="20" width="1160" height="2160" fill="none" stroke="#111" stroke-width="2" />
    
    <text x="335" y="2145" class="disclaimer-text">REPRODUCTION DOCUMENT — Not an original L&amp;R Mfg. Co. technical publication.</text>
    <text x="335" y="2160" class="disclaimer-text">Reverse-engineered from direct physical measurement of specimen S/N 13505. Curated by Hobbs R.E., 2026. For restoration reference only.</text>

    <rect x="650" y="2050" width="530" height="130" fill="#fff" stroke="#111" stroke-width="2" />
    <line x1="650" y1="2085" x2="1180" y2="2085" stroke="#111" stroke-width="2" />
    <line x1="650" y1="2135" x2="1180" y2="2135" stroke="#111" stroke-width="1" />
    
    <line x1="765" y1="2135" x2="765" y2="2180" stroke="#111" stroke-width="1" />
    <line x1="875" y1="2135" x2="875" y2="2180" stroke="#111" stroke-width="1" />
    <line x1="1065" y1="2135" x2="1065" y2="2180" stroke="#111" stroke-width="1" />

    <text x="915" y="2073" class="header-text">L&amp;R MFG. CO. — MASTER CLEANING MACHINE</text>
    
    <text x="660" y="2105" class="label-text">DRAWING TITLE:</text>
    <text x="660" y="2123" class="value-text" font-weight="bold">MOTOR ASSEMBLY EXPLODED PROFILE (REV F)</text>
    
    <text x="665" y="2152" class="label-text">ENGINEER:</text>
    <text x="665" y="2170" class="value-text">Hobbs R.E.</text>
    
    <text x="775" y="2152" class="label-text">DATE:</text>
    <text x="775" y="2170" class="value-text">June 12, 2026</text>
    
    <text x="885" y="2152" class="label-text">METADATA CONTROL:</text>
    <text x="885" y="2170" class="value-text">Rev F: inserted ARM-013 x4 phenolic washer stack between BRG-001 and the ARM-001 upper journal; model nomenclature corrected to Master.</text>
    
    <text x="1075" y="2152" class="label-text">STATUS:</text>
    <text x="1075" y="2170" class="value-text" font-weight="bold" fill="#228b22">RELEASED</text>

    <line x1="600" y1="50" x2="600" y2="2000" class="centerline-main" />
    <line x1="508" y1="100" x2="508" y2="1500" class="centerline-bolt" />
    <line x1="692" y1="100" x2="692" y2="1500" class="centerline-bolt" />

    <g id="UH-001">
        <path d="M 472,332 L 472,220 C 472,120 728,120 728,220 L 728,332 Z" class="outline fill-alum" />
        <rect x="472" y="322" width="256" height="10" class="outline fill-alum" />
        <path d="M 570,128 L 630,128 L 630,120 L 570,120 Z" class="outline fill-alum" />
        <line x1="508" y1="200" x2="508" y2="332" stroke="#fff" stroke-width="6" stroke-dasharray="10,4" />
        <line x1="692" y1="200" x2="692" y2="332" stroke="#fff" stroke-width="6" stroke-dasharray="10,4" />
        
        <path class="leader" marker-start="url(#dot)" d="M 500,160 L 400,160 L 350,140" />
        <text x="340" y="140" class="label-text" text-anchor="end">UH-001 UPPER MOTOR HOUSING</text>
    </g>

    <g id="STR-001">
        <rect x="480" y="380" width="240" height="59" class="outline" fill="url(#hatch-iron)" />
        <rect x="530" y="375" width="40" height="69" class="outline" fill="url(#hatch-copper)" />
        <rect x="630" y="375" width="40" height="69" class="outline" fill="url(#hatch-copper)" />
        <rect x="570" y="380" width="60" height="59" fill="#f8f9fa" />
        <circle cx="508" cy="409.5" r="4" fill="#f8f9fa" class="outline" />
        <circle cx="692" cy="409.5" r="4" fill="#f8f9fa" class="outline" />

        <path class="leader" marker-start="url(#dot)" d="M 700,409 L 800,409 L 850,390" />
        <text x="860" y="390" class="label-text" text-anchor="start">STR-001 STATOR FIELD ASSEMBLY</text>
        
        <path class="leader" marker-start="url(#dot)" d="M 670,390 L 750,340 L 850,340" />
        <text x="860" y="340" class="label-text" text-anchor="start">STR-005 RIGHT FIELD COIL</text>
    </g>

    <g id="BRG-001">
        <circle cx="600" cy="507" r="22.5" class="outline" fill="url(#hatch-bronze)" />
        <rect x="584" y="480" width="32" height="54" class="outline" fill="url(#hatch-bronze)" />
        <rect x="590" y="480" width="20" height="54" fill="#f8f9fa" class="outline" stroke-dasharray="4,2" />
        
        <path class="leader" marker-start="url(#dot)" d="M 577,507 L 450,507 L 400,490" />
        <text x="390" y="490" class="label-text" text-anchor="end">BRG-001 UPPER BEARING (0.560" BALL)</text>
    </g>

    <g id="ARM-013-STACK">
        <rect x="578" y="546" width="44" height="3" class="outline fill-phenolic" />
        <rect x="578" y="549" width="44" height="3" class="outline fill-phenolic" />
        <rect x="578" y="552" width="44" height="3" class="outline fill-phenolic" />
        <rect x="578" y="555" width="44" height="3" class="outline fill-phenolic" />
        
        <path class="leader" marker-start="url(#dot)" d="M 622,550 L 750,550 L 800,540" />
        <text x="810" y="545" class="label-text" text-anchor="start">ARM-013 PHENOLIC x4</text>
    </g>

    <g id="ARM-001">
        <rect x="590" y="580" width="20" height="68" class="outline fill-alum" />
        <rect x="561" y="648" width="78" height="10" class="outline fill-brass" />
        <rect x="561" y="658" width="78" height="32" class="outline fill-comm" />
    
        <line x1="576" y1="658" x2="576" y2="690" stroke="#7c2d12" stroke-width="1.5" />
        <line x1="592" y1="658" x2="592" y2="690" stroke="#7c2d12" stroke-width="1.5" />
        <line x1="608" y1="658" x2="608" y2="690" stroke="#7c2d12" stroke-width="1.5" />
        <line x1="624" y1="658" x2="624" y2="690" stroke="#7c2d12" stroke-width="1.5" />

        <polygon points="561,690 639,690 660,728 540,728" class="outline" fill="url(#hatch-copper)" />
        <rect x="540" y="728" width="120" height="62" class="outline" fill="url(#hatch-iron)" />
        <line x1="540" y1="740" x2="660" y2="740" stroke="#000" stroke-width="1.5" />
        <line x1="540" y1="755" x2="660" y2="755" stroke="#000" stroke-width="1.5" />
        <line x1="540" y1="770" x2="660" y2="770" stroke="#000" stroke-width="1.5" />

        <polygon points="540,790 660,790 652,821 548,821" class="outline" fill="url(#hatch-copper)" />
        <rect x="548" y="821" width="104" height="26" class="outline fill-alum" />
        <line x1="565" y1="821" x2="565" y2="847" stroke="#000" stroke-width="1" />
        <line x1="582" y1="821" x2="582" y2="847" stroke="#000" stroke-width="1" />
        <line x1="618" y1="821" x2="618" y2="847" stroke="#000" stroke-width="1" />
        <line x1="635" y1="821" x2="635" y2="847" stroke="#000" stroke-width="1" />

        <rect x="577" y="847" width="46" height="8" class="outline fill-brass" />
        <rect x="588.8" y="855" width="22.4" height="150" class="outline fill-alum" />
        
        <path class="leader" marker-start="url(#dot)" d="M 640,674 L 750,674 L 800,660" />
        <text x="810" y="660" class="label-text" text-anchor="start">ARM-006 COMMUTATOR</text>
        
        <path class="leader" marker-start="url(#dot)" d="M 660,759 L 750,759 L 800,770" />
        <text x="810" y="770" class="label-text" text-anchor="start">ARM-002 ARMATURE CORE</text>
        
        <path class="leader" marker-start="url(#dot)" d="M 652,834 L 750,834 L 800,850" />
        <text x="810" y="850" class="label-text" text-anchor="start">ARM-007 COOLING FAN</text>
        
        <path class="leader" marker-start="url(#dot)" d="M 600,950 L 750,950 L 800,970" />
        <text x="810" y="970" class="label-text" text-anchor="start">SHF-003 LOWER JOURNAL (Ø0.280")</text>
    </g>

    <g id="ARM-PHENOLIC-WASHER-STACK">
        <rect x="575" y="1012" width="50" height="4" class="outline fill-phenolic" />
        <rect x="575" y="1016" width="50" height="4" class="outline fill-phenolic" />
        <rect x="575" y="1020" width="50" height="4" class="outline fill-phenolic" />
        
        <rect x="580" y="1024" width="40" height="4" class="outline fill-phenolic" />

        <path class="leader" marker-start="url(#dot)" d="M 625,1016 L 750,1016 L 800,1010" />
        <text x="810" y="1010" class="label-text" text-anchor="start">ARM-011 PHENOLIC WASHER x3</text>
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

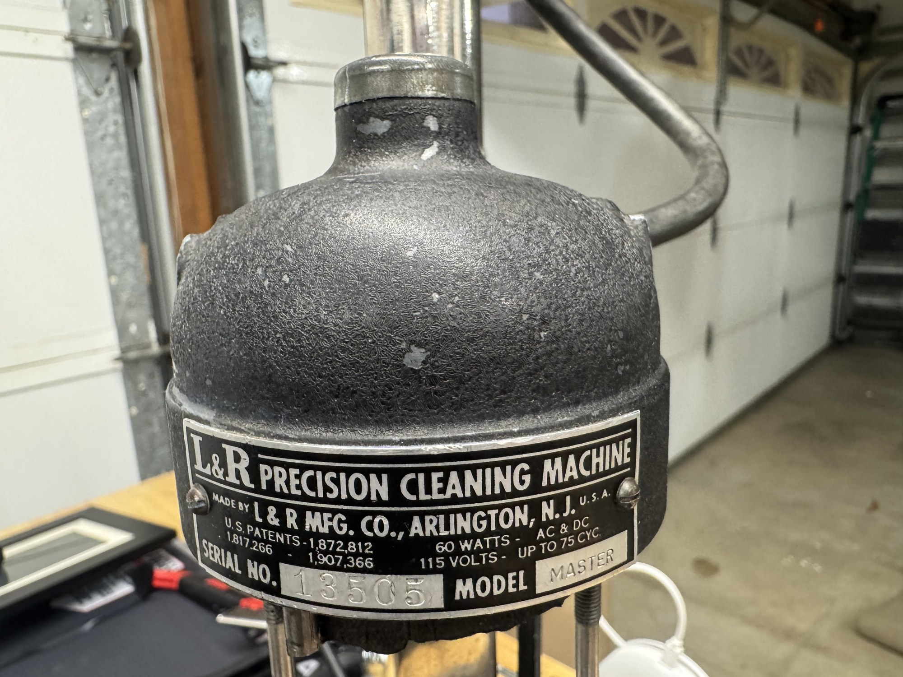
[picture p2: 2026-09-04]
photos/highlights/01-as-found-motor-head.jpg

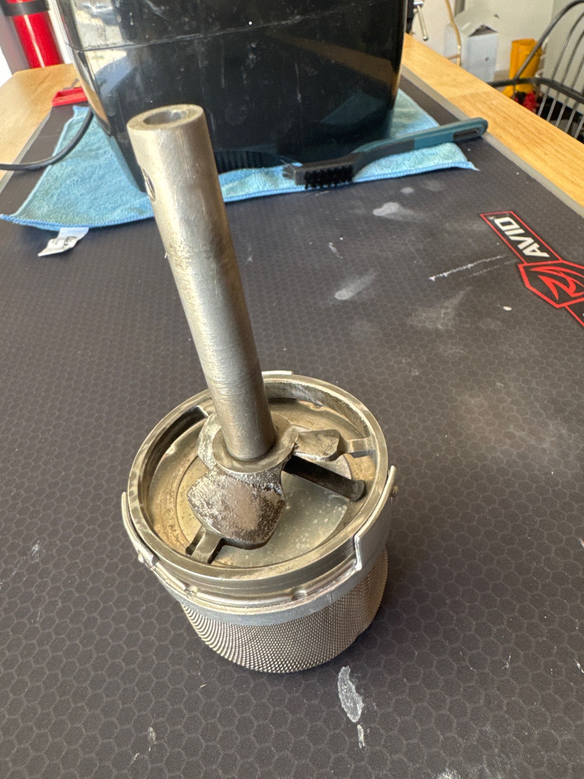
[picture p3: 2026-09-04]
photos/highlights/09-basket-spindle-cleaned.jpg

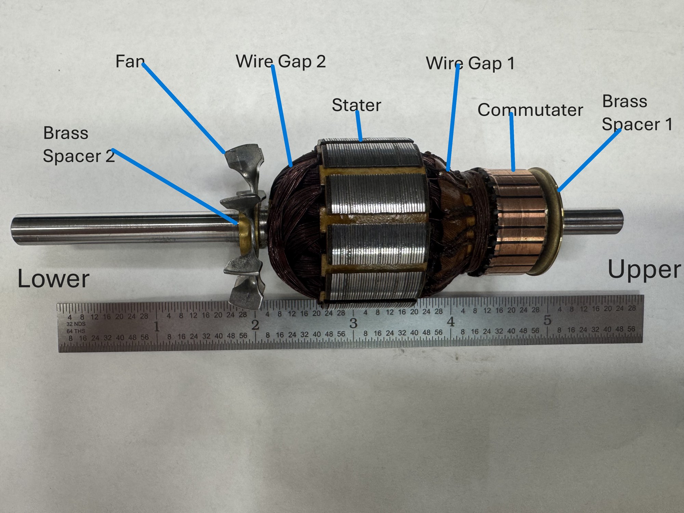
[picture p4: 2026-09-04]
photos/highlights/04-armature-annotated.jpg

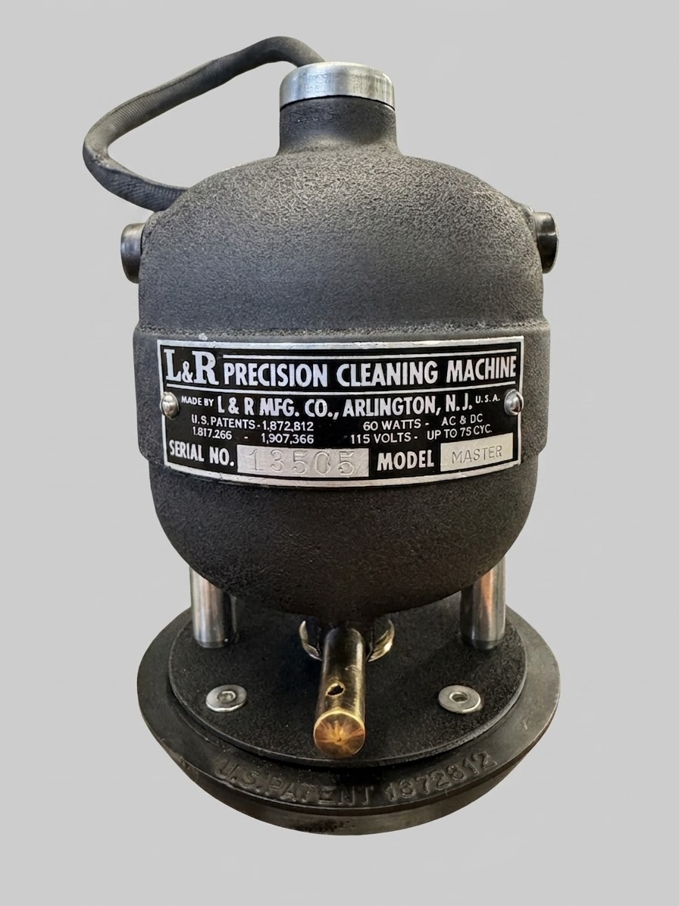
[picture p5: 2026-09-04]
photos/finished/LR-13505-finished-03-motorhead-nameplate.jpg

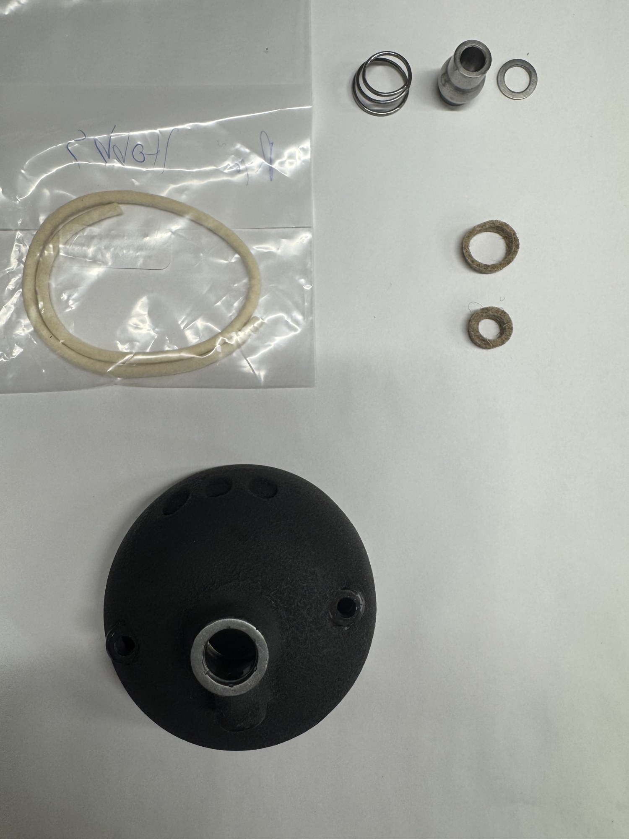
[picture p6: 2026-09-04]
photos/highlights/05-bearing-wick-felt-kit.jpg

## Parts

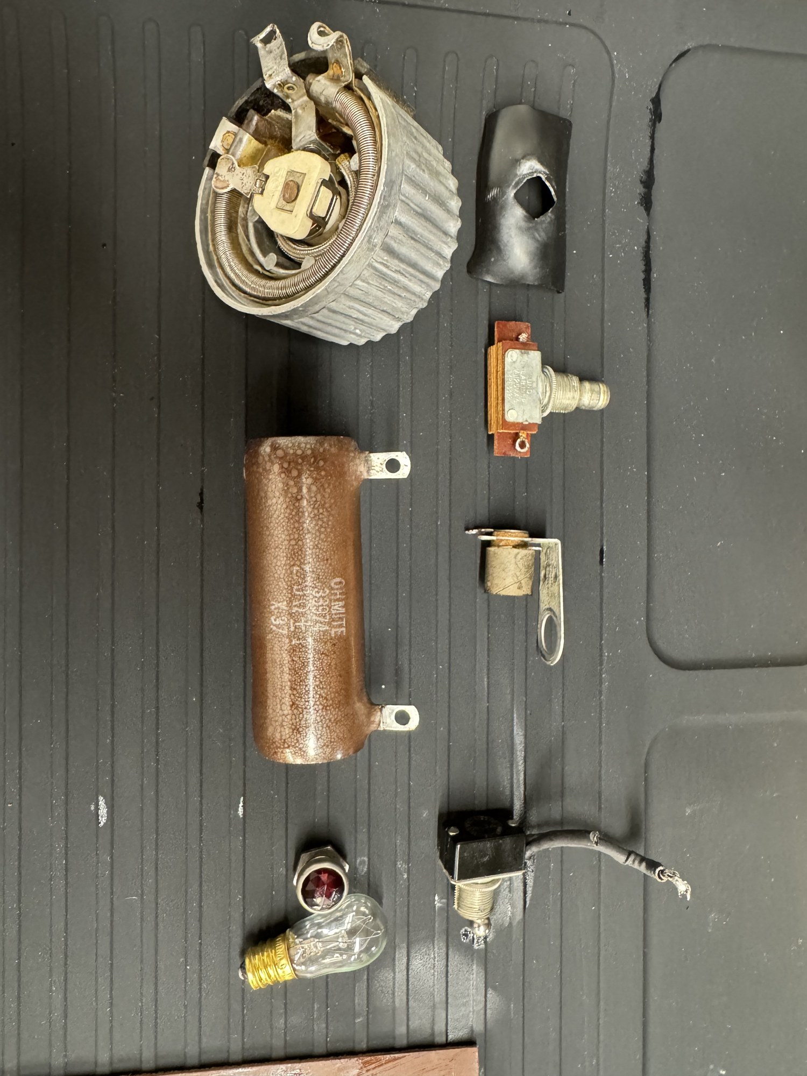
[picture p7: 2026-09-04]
photos/highlights/11-control-components.jpg

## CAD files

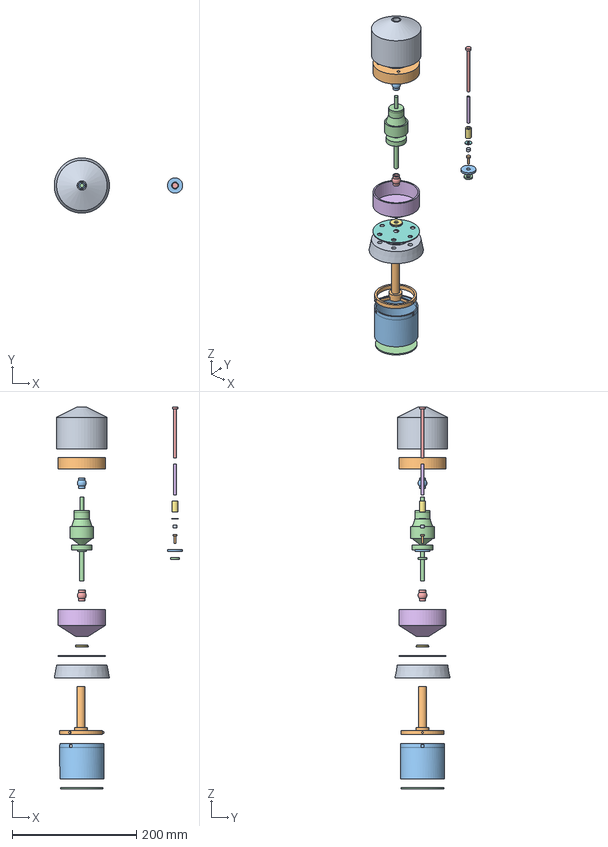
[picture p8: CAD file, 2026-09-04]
cad/assembly/L_and_R_Master_Exploded.step
206.7 x 88.9 x 614.6 mm

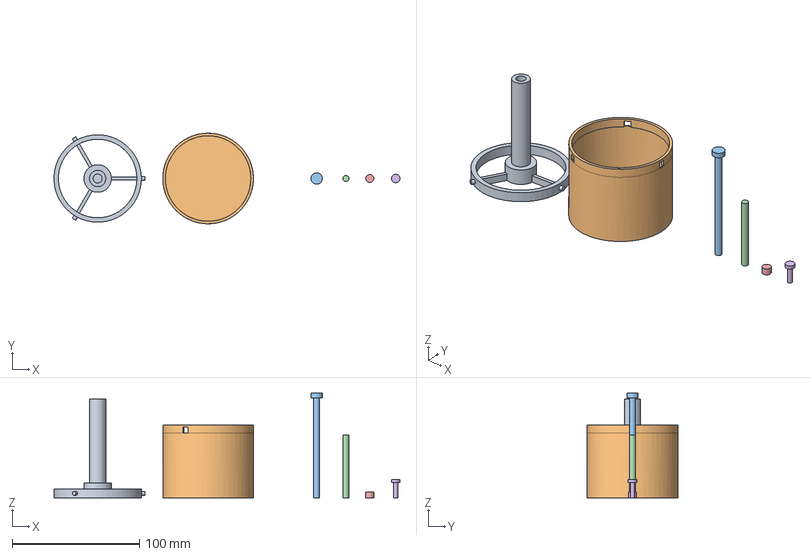
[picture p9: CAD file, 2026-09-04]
cad/batch2/Batch2_Spindle_Basket.FCStd
271.6 x 71.1 x 82.0 mm
SPN_002_Basket_Drive_Spindle_APPROX
BSK_002_Mesh_Basket_cup
FLG_002_Housing_Bolt
STR_008_Stator_Screw
SPN_005_Set_Screw
SPN_007_Brass_Screw

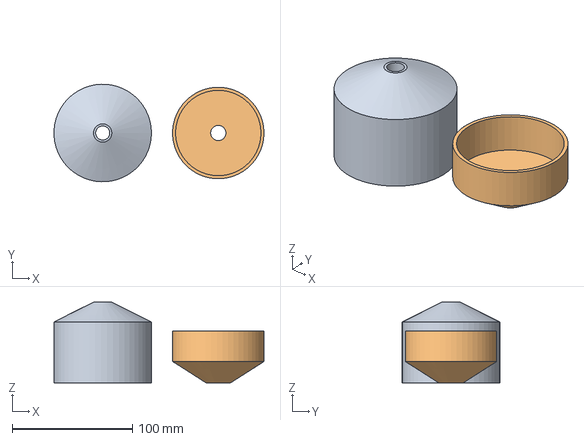
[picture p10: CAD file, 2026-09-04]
cad/batch3/Batch3_Housings.FCStd
174.9 x 81.2 x 67.3 mm
UH_001_Upper_Housing_APPROX
LH_001_Lower_Housing_APPROX

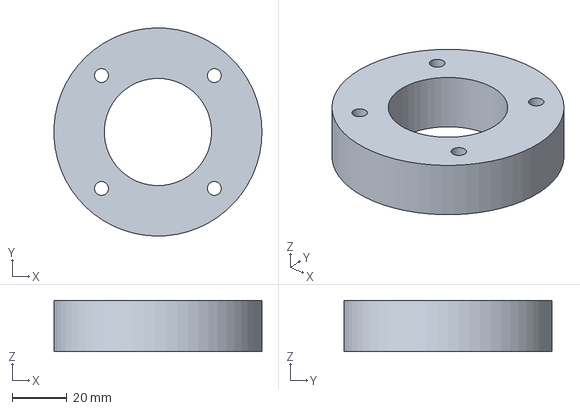
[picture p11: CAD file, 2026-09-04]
cad/batch4/STR_001_Stator_Ring_APPROX.step
76.1 x 76.2 x 18.7 mm

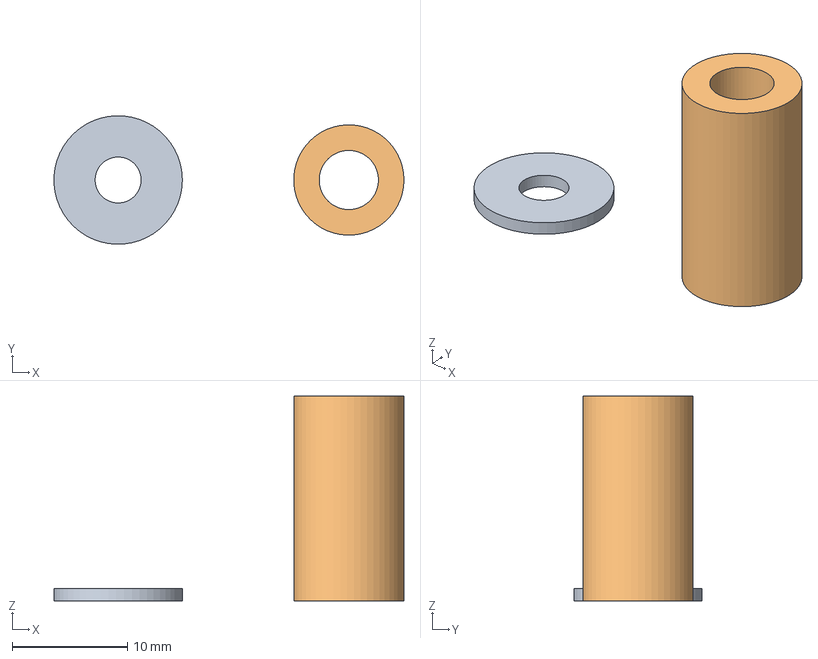
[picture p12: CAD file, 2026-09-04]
cad/pilot/PLT_pilot.FCStd
30.3 x 11.1 x 17.8 mm
PLT_006_Gasket_Deck_Washer
PLT_004_Mount_Standoff_Tube

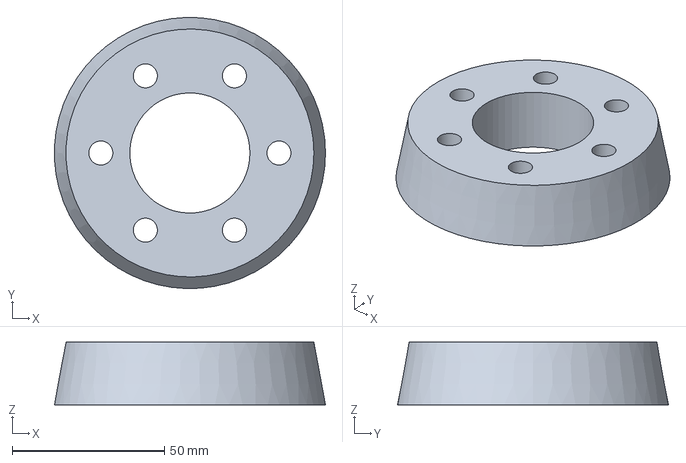
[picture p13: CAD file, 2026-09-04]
cad/batch1/PLT_002_Tapered_Jar_Seal_Gasket.step
88.9 x 88.9 x 20.5 mm

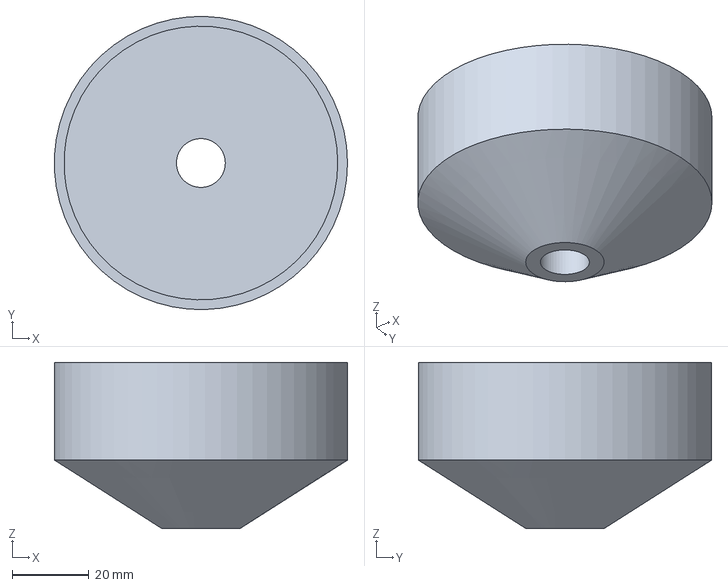
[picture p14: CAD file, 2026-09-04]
cad/batch3/LH_001_Lower_Housing_APPROX.step
76.1 x 76.2 x 43.2 mm

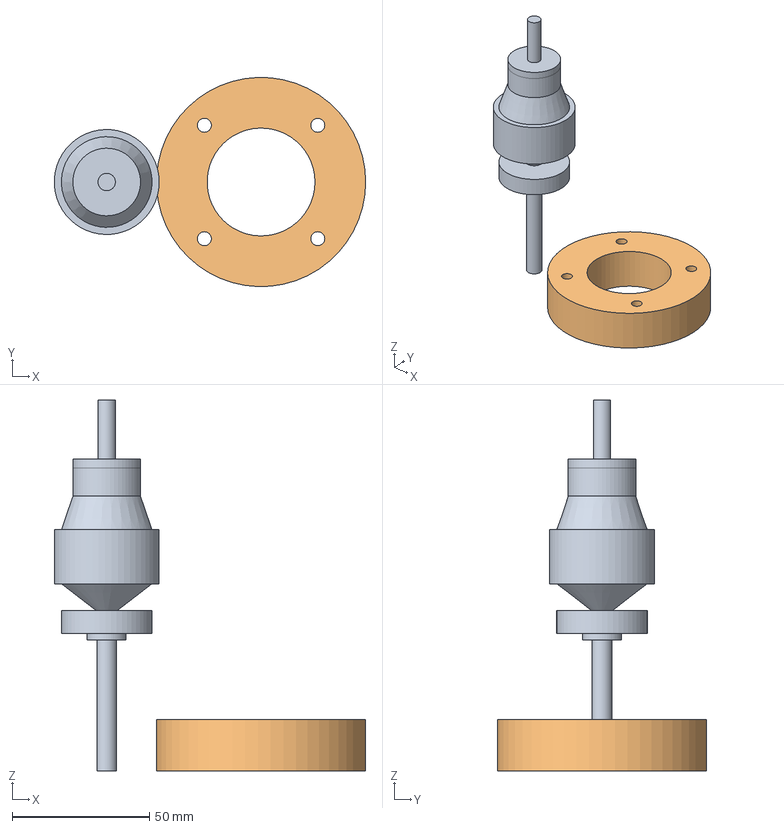
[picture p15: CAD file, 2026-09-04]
cad/batch4/Batch4_Rotor_Stator.FCStd
113.4 x 76.2 x 135.1 mm
ARM_001_Armature_Rotor_APPROX
STR_001_Stator_Ring_APPROX

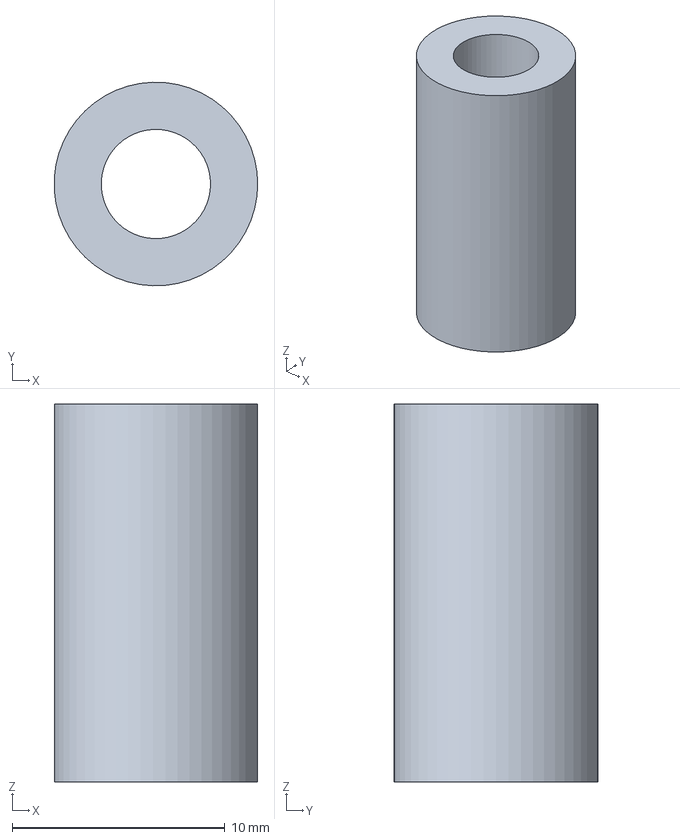
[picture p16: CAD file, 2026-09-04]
cad/pilot/PLT-004_Mount_Standoff_Tube.step
9.55 x 9.56 x 17.8 mm

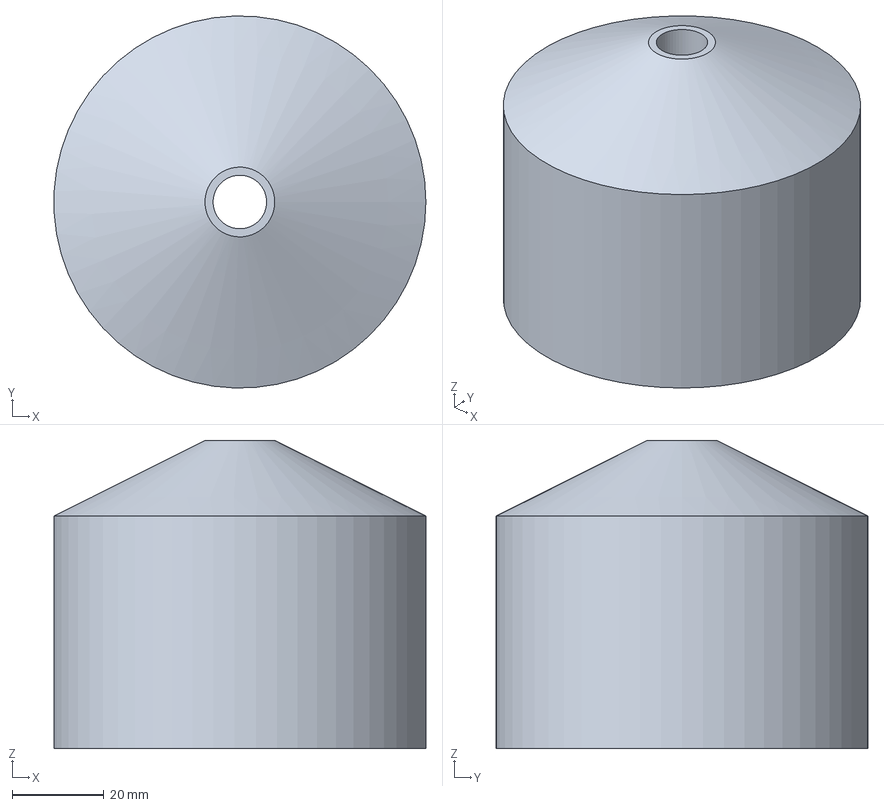
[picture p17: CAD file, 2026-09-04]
cad/batch3/UH_001_Upper_Housing_APPROX.step
81.2 x 81.2 x 67.3 mm

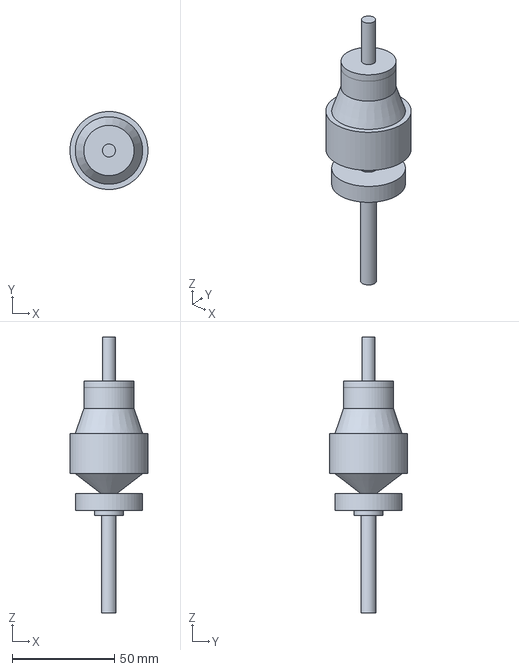
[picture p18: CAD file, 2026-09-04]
cad/batch4/ARM_001_Armature_Rotor_APPROX.step
38.2 x 38.2 x 135.1 mm

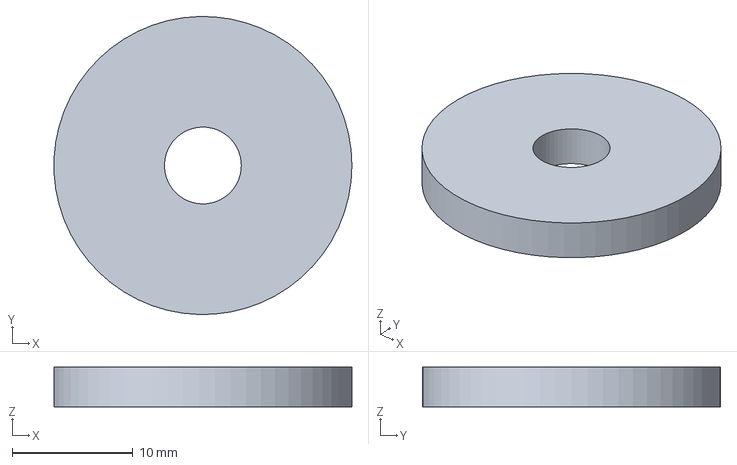
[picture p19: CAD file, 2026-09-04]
cad/batch1/ARM_008_Brass_Collar_Upper.step
24.6 x 24.6 x 3.30 mm

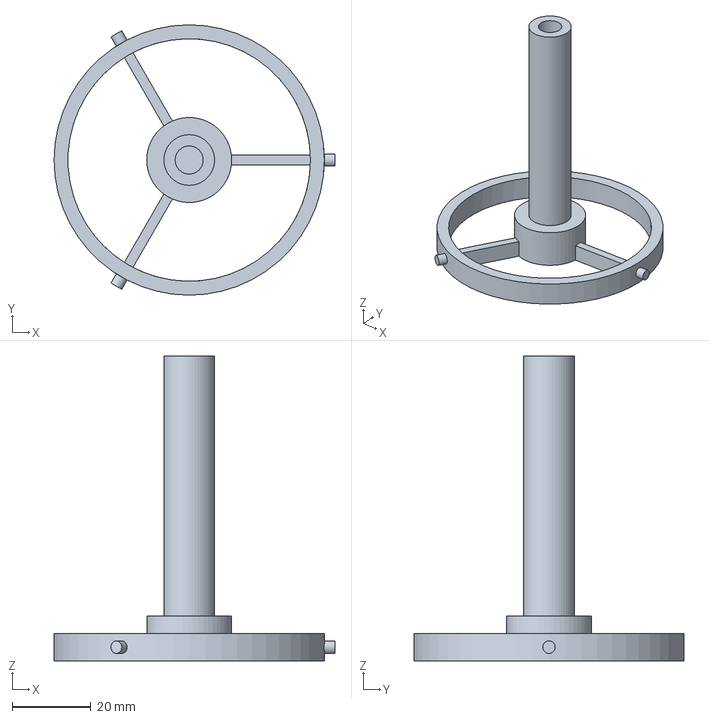
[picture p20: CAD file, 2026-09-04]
cad/batch2/SPN_002_Basket_Drive_Spindle_APPROX.step
71.3 x 68.7 x 77.5 mm

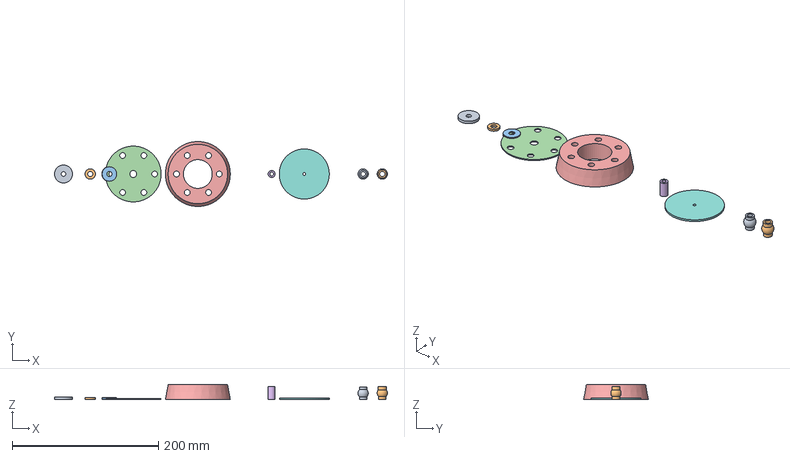
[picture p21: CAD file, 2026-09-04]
cad/batch1/Batch1_Revolved.FCStd
455.8 x 88.9 x 20.5 mm
ARM_008_Brass_Collar_Upper
ARM_009_Brass_Collar_Lower
ARM_010_Thrust_Washer_stepped
PLT_001_Platform_Disk
PLT_002_Tapered_Jar_Seal_Gasket
PLT_004_Mount_Standoff_Tube
PLT_006_Gasket_Deck_Washer
BSK_003_Basket_Lid
BRG_001_Upper_Bearing
BRG_002_Lower_Bearing

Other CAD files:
cad/batch1/PLT_004_Mount_Standoff_Tube.step
cad/batch2/BSK_002_Mesh_Basket_cup.step
cad/batch1/BRG_001_Upper_Bearing.step
cad/batch1/PLT_001_Platform_Disk.step
cad/assembly/L_and_R_Master_Exploded.FCStd
cad/batch1/ARM_009_Brass_Collar_Lower.step
cad/batch1/ARM_010_Thrust_Washer_stepped.step
cad/batch1/BRG_002_Lower_Bearing.step
cad/batch1/BSK_003_Basket_Lid.step
cad/batch1/PLT_006_Gasket_Deck_Washer.step
cad/batch2/FLG_002_Housing_Bolt.step
cad/batch2/SPN_005_Set_Screw.step
cad/batch2/SPN_007_Brass_Screw.step
cad/batch2/STR_008_Stator_Screw.step
cad/pilot/PLT-006_Gasket_Deck_Washer.step

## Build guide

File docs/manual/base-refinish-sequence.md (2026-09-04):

# Base Casting (BAS-001) Refinish & Cast-Letter Restoration Sequence

> **REPRODUCTION DOCUMENT** — restoration procedure for specimen S/N 13505. Curated by Hobbs R.E., 2026. Best-judgment method (no factory refinish spec exists).

Detailed cosmetic-refinish workflow for the **stripped BAS-001 base casting** — heavy metalwork, epoxy inlay to rebuild worn cast lettering (**"OFF"** on the tongue + the **"L&R MASTER"** smile-arc = BAS-005), seal, and the VHT wrinkle topcoat matching the motor housings (R-2). Slots into control-unit roadmap **Phase 1 (prep) → Phase 2 (paint)**, after Citristrip.

## Operator sequence (as provided 2026-06-27)
**Phase 1 — Heavy metalwork & structural prep**
1. **Internal grinding** — grind interior raised burrs around the center-post holes flush (so the rechromed post NCK-001 seats cleanly; ties to the BAS-006 fit note).
2. **External leveling** — file heavy factory casting lines; palm-sand the wide flat exterior areas.
3. **Initial trace** — Dremel 108 bit, lightly trace the faint "OFF" boundaries to keep guidelines visible.
4. **Chemical clean** — degrease inside + out (acetone or IPA); remove all aluminum dust + oils.

**Phase 2 — Base seal & epoxy inlay**
5. **Anchor coat** — thin coat VHT Self-Etching Primer over the whole housing, in + out; 30–60 min dry.
6. **J-B Weld fill** — J-B Weld **High Heat** epoxy: pack deep exterior pits, smooth casting lines, build a flat "plaque" over the "OFF" area; cure 24 h.
7. **Block sanding** — hard block + 220-grit; sand the cured epoxy flush with the surrounding aluminum.

**Phase 3 — Sculpting & sealing the letters**
8. **Pre-carve** — Dremel 108 + a drop of WD-40; re-carve the "OFF" trenches into the smooth epoxy/aluminum inlay.
9. **High-build sealer** — 2–3 coats VHT Engine Enamel Primer (in + out); fills micro-pinholes, seals the carvings.
10. **Letter color coat** — spray the "OFF" area the finished letter color (gloss white/silver/red high-temp enamel); paint deep into trenches; 24 h dry.

**Phase 4 — Masking & the wrinkle finish**
11. **Liquid mask** — fine brush/Q-tip; thin Vaseline (or liquid mask) into the trenches + on the letter faces only.
12. **Interior finishing** (optional) — mask exterior, spray smooth (non-wrinkle) VHT engine paint over the interior primer.
13. **VHT wrinkle** — 3 heavy cross-hatched coats of wrinkle paint over the exterior.
14. **Heat + sun bake** — flash 20 min in shade; heat gun in sweeping circles to draw uniform wrinkle; then 3–4 h in hot sun to fully cure.
15. **Wipe reveal** — after fully cool, firmly wipe the "OFF" area with microfiber; wrinkle paint over the greasy mask slides off, revealing the pre-painted letters.

---

## ✅ DECISION 2026-07-11 — LETTERS STAY MONOCHROME (factory-correct)
Operator decision: **do NOT do a separate letter color-fill / wipe-back.** The cast relief lettering ("L&R MASTER" arc + "OFF" + "ON->") gets shot with the same VHT wrinkle as the whole casting and left that way — raised letters read by relief + shadow, not by contrasting color. This is how the factory did it (as-cast relief, single finish). **This SUPERSEDES all the "color letters last / wipe-back" steps below** (old steps 10, 11, 15 and the wipe-back row in the recoat table). No Vaseline mask, no Testors fill, no wipe reveal — just even wrinkle over the letters like the rest of the part.

## ⚠️ CLAUDE TECHNICAL REVIEW (best-judgment — read before executing)
**🔴 Steps 11/15 — Vaseline mask under a HIGH-HEAT wrinkle cure is the biggest risk. RECOMMEND CHANGING.**
Petroleum jelly melts ~105 °F and thins; the wrinkle cure is ~350 °F (heat gun) + sun bake → the Vaseline **liquefies and can wick/migrate into the surrounding wrinkle paint**, causing fisheyes / un-wrinkled contaminated patches / adhesion failure (petroleum is the classic paint-adhesion enemy).
- **PREFERRED ALTERNATIVE: do the letters LAST.** Wrinkle-coat + fully cure the whole housing first, THEN fill the "OFF"/"L&R MASTER" recesses with color via **paint-fill wipe-back** (the validated CTL-002 knob method) — no mask, no contamination, wrinkle stays pristine.
- If keeping a mask, use a **mechanical high-temp mask** removed after cure, not petroleum.

**🟡 Steps 5→6 REORDERED (confirmed w/ operator) — J-B Weld bonds best to ABRADED BARE METAL, not primer. FILL FIRST, PRIME AFTER.** Corrected stack (bottom→top): (a) metalwork; (b) **key the fill areas to bright bare aluminum + degrease**; (c) **J-B Weld High Heat on bare metal → cure**; (d) **sand flush → carve letters**; (e) **degrease again**; (f) **etch primer over the WHOLE housing** (locks the bare aluminum + seals over the cured epoxy); (g) **enamel high-build primer**; (h) → color / letters / wrinkle. *(Scuff the glassy cured epoxy before priming so the etch primer keys; degrease right before the etch coat.)* Net: epoxy grabs bare metal (strongest bond) AND the etch primer still protects every exposed-aluminum spot because it goes over the fill. Supersedes the original "etch primer then epoxy" order.

**🟢 Step 6 — J-B Weld HIGH HEAT is the correct filler (upgrade over "Bondo").** Polyester body filler can shrink/outgas/soften at the 350 °F wrinkle bake; J-B Weld High Heat (~450–550 °F) survives it. (Roadmap updated: prefer J-B Weld High Heat over Bondo for the heat-cure context.)

**🟢 Steps 13–14 — keep IDENTICAL to the motor-housing R-2 process** (same VHT wrinkle product, 3-coat crosshatch, ~350 °F draw, cure) so the base texture MATCHES the already-finished housings — cohesion across the machine.

**Notes:** (1) do the **final degrease right before priming with SOLVENT (IPA/acetone), NOT Citranox** — solvent flashes off residue-free; after all sanding/carving dust. (2) The sequence names "OFF" — give the **"L&R MASTER" relief (BAS-005)** the same letter treatment. (3) Consider a **practice Dremel carve on scrap J-B Weld** first — Step 8 is freehand and unforgiving.

## Recoat windows & timing (VHT aerosol rule)
**Golden rule for all VHT/Dupli-Color aerosols: recoat WITHIN ~30 min, OR wait 48 h (then scuff). Never recoat in the 30 min → 48 h dead zone** — the fresh solvent re-softens a half-cured skin underneath = wrinkle/lift (same failure as the epoxy-margin risk). Warm SoCal sun shortens every flash time below.

| Transition | Wait | Notes |
|---|---|---|
| Etch primer → enamel primer | Flash **10–20 min** (touch-dry), then recoat within the 30-min window | Do both primers back-to-back in ONE session. Miss the window → wait 48 h + scuff with gray Scotch-Brite before enamel. |
| Enamel primer coat → next enamel coat | **A few min** apart (light flash), all inside 30 min | 2–3 build coats total. |
| Enamel primer → block-sand | Let fully cure first (**several hrs+**, or overnight) | Only if leveling; not mandatory. |
| Primer → VHT wrinkle | Wrinkle goes over cured primer; **re-mask holes with BAKE-PROOF plugs first** (green tape fails at 350°F) | Match motor-housing R-2 texture. |
| Wrinkle coat → next wrinkle coat | Per R-2: 3-coat crosshatch, coats a few min apart, then ~350°F heat-draw | Keep IDENTICAL to motor housings. |
| Wrinkle fully cured → letter color (wipe-back) | Wrinkle **fully cured + cool** before filling letters | No Vaseline mask; wipe-back fill only. |

*(Confirm against the actual can label — VHT print the specific recoat/cure times; the 30-min / 48-h rule is the VHT/Dupli-Color default when the can is unavailable.)*

## Progress log
- **2026-06-27:** BAS-001 stripped to bare aluminum; rough areas ground/sanded smooth; cleaned w/ **Citranox** + scrubbed, **rinsed under tap water a few min** (detergent flushed — epoxy-bond concern resolved), dried; **J-B Weld epoxy applied over the "OFF" area** (on bare metal — correct order). ✅ Fill-on-bare-metal step done. NEXT: 24 h cure → block-sand flush (knock down the epoxy peak; skim/prime any pinholes) → carve "OFF" (leave BARE — no pre-color) → **final SOLVENT degrease** (not Citranox) → etch primer (soon, before Al re-oxidizes) → enamel high-build primer → wrinkle → **color the carved letters LAST via wipe-back**. ⚠️ Citranox is alkaline/water-based — ensure it was rinsed + dried well under the epoxy (watch for lifting when sanding). Base brackets (BAS-008) + PLT-001 disk stripped in the same batch. **Photos filed** → `photos/base-refinish/` (BR-01…BR-05, see that folder's `figure-index.md`): BR-01 stripped plan, BR-02 J-B Weld "OFF" fill macro, BR-03 3/4, BR-04 post-boss side, BR-05 wells/relief plan.
- **2026-07-08:** J-B Weld cured; **"OFF" lettering recut** with Dremel flex-shaft + #008 bit (Step 8 done); **cured epoxy block-sanded flush** (Step 7 done). Remaining epoxy is where it filled cast lines/pits — good. ✅ Fill + carve + flush-sand complete. **NEXT (locked order):** (1) final SOLVENT degrease — IPA/acetone, NOT Citranox — + tack cloth (remove sand dust/oils); confirm epoxy faces are matte (scuff if glossy); blow out the recut "OFF" trenches; (2) **etch primer** — thin anchor coat over whole housing, get it on before bare Al re-oxidizes; (3) **VHT engine enamel high-build primer** 2–3 coats; (4) **VHT wrinkle** 3-coat crosshatch + ~350°F heat draw (match motor-housing R-2 texture); (5) **color "OFF" + "L&R MASTER" (BAS-005) LAST via wipe-back** after wrinkle cures — no Vaseline mask. ⚠️ Watch epoxy margins on the first etch coat for lift/fisheye (tell-tale for trapped Citranox/water).
- **2026-07-08 (cont.):** Prep complete — initial sanding, dust blow-out, **IPA solvent cleanse**, and **hole masking done** (green tape/putty plugs in all fastener holes + post socket BAS-006 + the 3 small parts BAS-008/carrier/PLT-001; wells left open). ✅ Ready for etch primer. ⚠️ **RE-MASK BEFORE WRINKLE:** green painter's tape/putty is rated ~250°F — fine for the air-dry PRIMER coats, but it will bake on/scorch at the ~350°F wrinkle stage. Before the wrinkle coat, swap to bake-proof masks (silicone high-temp plugs / stainless bolts threaded in / polyimide-Kapton tape). Post socket (BAS-006): keep plugged; test-fit rechromed NCK-001 (thicker) before final assembly, lap if snug. R-5 ground spot: no need to reserve now — scrape to bright bare Al at reassembly.
- **2026-07-09:** ✅ **Etch primer + VHT enamel primer complete, inside + outside** — BAS-001 casting + NCK-002 carrier + PLT-001 disk + BAS-008 tang all in uniform grey primer; coverage clean (no runs), wells done, "OFF/L&R MASTER/ON" relief crisp. Primer curing; **VHT wrinkle ~24–48 h out.** PRE-WRINKLE CHECKLIST: (1) ⚠️ **swap green tape → bake-proof masks** (silicone plugs / stainless bolts / Kapton) — green tape fails at the ~350°F wrinkle bake; (2) **light scuff (gray Scotch-Brite) + tack wipe** — primer will be fully cured / past recoat window, so key it mechanically; (3) **wells decision: wrinkle exterior ONLY**, leave wells in primer (or smooth topcoat); mask well bores if jar/heater-cylinder fit is tight (texture eats clearance); (4) **warm part + can, midday sun**; (5) **wrinkle goes HEAVY** (3-coat crosshatch vert/horiz/thick) + ~350°F heat-draw — match motor-housing R-2 texture; (6) letters stay MONOCHROME — shoot wrinkle over them, no separate color fill (factory-correct decision 2026-07-11).
- **2026-07-11 — ✅ VHT WRINKLE APPLIED (paint day).** Parts pre-warmed in SoCal sun. Masks: blue tape + cardboard plugs on fit surfaces (BAS-006 square socket, screw holes, NCK-002 square bore + mount holes, PLT-001 holes); feet/exterior exposed. **All coats applied to all 4 parts** (BAS-001 base + NCK-002 carrier + PLT-001 disk + BAS-008 tang) at **12:35 PM PST**. Heat-gun draw: **~5–10 min, oscillating/moving**, backed off each area the moment crinkle grain formed, then stopped all heat. **Now curing in direct sun.** Letters shot monochrome (no wipe-back), per decision. **NEXT:** sun-bake 3–4 h min (all afternoon ideal) → bring inside before dusk → let sit undisturbed **48–72 h** for full hardness/off-gas → then pull masks WARM (re-warm any stubborn tape), verify fit surfaces clean → test-fit rechromed NCK-001 in BAS-006 socket → mock up assembly to capture the last open dim (**BAS-008 installed tang projection height**). ⚠️ Full chemical cure ~5–7 days; no hard reassembly contact / no clamping against the fresh wrinkle for 24 h+.
- **2026-07-11 (eve) — CURED-RESULT ASSESSMENT (in-sun photos, ~5 h into cure).** Overall: ✅ **GOOD, keeper — no full re-do.** Coverage complete, color right, no bare/thin spots. **Lettering reads great** (OFF / ON-> / L&R MASTER crisp by relief shadow — monochrome decision validated). **Issue = grain NON-uniform:** horizontal + most faces have heavy coarse grain (matches motor housings R-2), but VERTICAL faces (heater-well front face, parts of the tube, upper tongue by the neck) went **smoother/glossier/finer** — classic wrinkle-on-vertical: paint sagged/pooled thicker → thick wrinkle draws a flatter, glossier grain. NOT a wrinkle failure (texture everywhere); it's a **sheen + grain-size variation** (matte-coarse vs glossy-smooth) that catches the eye. Also minor proud clumps around the screw-hole bosses + lettering. **FINISH PLAN (after full cure, 72 h+ / full week for heavy spots):** (1) **light OVERALL gray Scotch-Brite pass** (ultra-fine gray only; test on a foot/underside first) — the key move is knocking gloss off the pooled areas so sheen matches the matte coarse areas; once sheen is uniform, grain-size variation reads as intentional/factory-like. (2) knock down the proud boss/letter clumps in the same pass. (3) **re-evaluate the 2-3 glossiest faces** (heater-well front face is the worst) — ONLY if still bugging after padding, spot-scuff + **light re-shoot + heat-gun draw** to add grain (wrinkle recoats onto itself). Expectation: uniform matte from padding gets ~90% there without re-spraying. ⚠️ Wait for hardness before padding (soft film smears/tears). Root-cause note for any future wrinkle: lighter coats on vertical faces to avoid sag/pool. **NEXT after finish pass:** pull masks warm → test-fit rechromed NCK-001 in BAS-006 → mock assembly → BAS-008 installed tang height → Phase 2 COMPLETE.

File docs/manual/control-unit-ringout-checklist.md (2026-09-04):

# Control Unit Electrical Ring-Out & Connection-Map Checklist
### L&R Master Watch Cleaning Machine, S/N 13505 — Control Unit (CU-001)

> **REPRODUCTION DOCUMENT** — Not an original L&R Mfg. Co. technical publication. Reverse-engineered from hands-on restoration of specimen S/N 13505. Curated by Hobbs R.E., 2026. For restoration reference only.

**Goal:** Produce a *complete, terminal-by-terminal, as-wired connection map* of the control unit **before any component is removed**, so the machine can be (a) drawn as a **verified as-found schematic** (replacing the inferred LR-ELEC-001) and (b) correctly re-wired with a safety ground. This is the **gate** for Phase-1 component removal — once a wire is cut or a lug disturbed without being logged, the actual as-wired state of *this* unit is lost (E-1690 only gives the generic factory intent, and this unit already shows prior-restoration rework).

**Accuracy doctrine (user directive — "very very very detailed and accurate"):**
- **Nothing leaves the casting until its every wire is logged AND photographed with tags visible.**
- Every physical terminal gets a **printed/tape tag** with its node name (below) **before** ringing out.
- Record **both ends** of every wire as a directed segment. A wire is not "done" until both endpoints are named.
- Capture **wire color, gauge (AWG/visual), insulation type** (cloth / rubber / PVC / bare-tinned), **length**, and **routing** (which side, through which hole, over/under what).
- Note **every splice, twist-solder joint, solder blob, terminal strip, or ring-lug** as its own node (these are the CTL-010 junctions).
- Tag confidence on EVERY reading: **(CONFIRMED)** metered/seen · **(EST.)** visual · **(SYN)** derived · **(ASSUMED)** not yet verified.

---

## 0. SAFETY & BENCH SETUP — do first, every session
- [ ] **Cord unplugged from mains the entire time.** All ring-out is **un-powered, DMM only.** (Powered tests happen later on the Rigol DP932A per the cold-check matrix — NOT here.)
- [ ] Original AC cord (CTL-008) already removed — confirm **no other energy source** (no capacitors expected in this resistive/series design; if any cap is found, short its leads with an insulated screwdriver and log it).
- [ ] DMM checks: fresh battery; verify continuity-beep on shorted leads (~0 Ω) and OL on open leads before trusting readings. Note meter lead resistance (zero it / subtract it — matters for low-Ω windings & the lamp).
- [ ] Good light + magnification on the underside; phone camera ready for macro.
- [ ] Soft jaws / no scratching the casting (it gets refinished, but threads/bores must stay clean).

## 0b. PRE-REMOVAL GATE & DISASSEMBLY CAPTURE (added 2026-06-25)
**Why:** the as-found joints are dirty/corroded with shared solder blobs → in-situ resistance readings are unreliable (a crusty joint adds ohms and can read a real connection as a false OPEN). So **accurate values are taken in-hand after removal on cleaned terminals**, not in-circuit. The connection map already came from a **visual wire-trace** (meter was only a cross-check), so it stands.

**Point of no return = cutting/desoldering before tagging.** Before the iron touches anything:
- [ ] **Tag every terminal** with its industry label (P1-L, RV1-W, S1-COM, R1-1, DS1-TIP, M1-S2 …) — tape flags.
- [ ] **Photograph each joint with tags visible** (most done — confirm every lug legible).
- [ ] **DS1 bulb rating read** ✅ (12 V/6 W).
- [ ] Optional quick **node-to-chassis** glance *if probes still reach bright metal* (else do post-removal).

**Disassembly capture — resolves the last two unknowns physically:**
- [ ] **As you unsolder each blob, count + tag EVERY wire entering it before it separates.** A blob joining N wires *is* a node — separating it directly shows the true structure (fixes the R1/DS1/S2/S1 series-vs-parallel mislabel on the spot).
- [ ] **Plunger (S1):** tag its wires, remove, **bench-test in-hand** — DMM continuity across all lug pairs in OUT vs IN → assign COM/NO/NC. Count its lugs first (3 ⇒ SPDT reverse: COM=hot, NO/NC=M1-S1/M1-S2).
- [ ] **RV1 wiper lug:** note which lug rides the moving arm = RV1-W (visual).

**In-hand metering discipline (clean readings):**
- [ ] Meter on the component's **own terminals**, never through a harness joint.
- [ ] **Clean the lug to bright metal** (fiberglass pen / fine abrasive / DeoxIt) before probing.
- [ ] **Zero leads** (short probes ≈ 0.3 Ω) before each value.
- [ ] Expected clean values: **R1 ~216 Ω**, RV1 ~50–394 Ω (done), DS1 cold a few Ω, motor windings low single digits.

## 1. AS-FOUND DOCUMENTATION — before touching anything
- [ ] **Overall underside photo**, oriented (mark FORWARD/tongue edge). Note orientation in every later photo.
- [ ] **Photograph each component in place** with its wires attached and undisturbed: rheostat, plunger, toggle, lamp socket, dropping resistor, terminal strip(s), grommet hole, neck-loom stubs.
- [ ] Note the **as-found state of the neck loom (CTL-009)**: which colored stubs (BLK/WHT/GRN) are present at the control-unit end, and what each currently lands on. (Recall: at the motor head, GREEN→brush, BLACK/WHITE→field reversing leads — so down here BLK/WHT/GRN must terminate on the rheostat/switch network.)
- [ ] Flag anything that looks **non-original / prior-rework**: modern wire nuts, replacement wire colors, re-soldered joints, added jumpers, drilled holes. Photograph + describe. (This unit is known to have been worked on before.)

## 2. NODE / TERMINAL REGISTRY — name everything, then tag it
Define and **physically tag** every terminal. Use these names (extend the numbering to match the actual lug count you find — count lugs and record it):

| Node | Component | Notes — confirm lug count at bench |
|---|---|---|
| **P1-H / P1-N** | (removed) AC line cord | Hot / Neutral — already cut; log where the stubs *used to* land if visible from solder marks. |
| **RH1-1 / RH1-2 / RH1-3** | Rheostat (CTL-001) | Toroidal pot. Expect 2 coil-end lugs + 1 wiper lug. **Identify the wiper** (see §5). Tag CW/CCW ends. |
| **S1-1 / S1-2 / (S1-3)** | Plunger switch (CTL-003) | Momentary. Count lugs — 2 = simple SPST; 3+ = SPDT/DPDT (reversing). Tag common (C) vs throws. |
| **S2-1 / S2-2 / (S2-3)** | Toggle switch (CTL-004) | Count lugs; tag common vs throws. |
| **LMP1-A / LMP1-B** | Pilot lamp socket (CTL-005) | A = center/tip contact, B = shell. |
| **R1-1 / R1-2 / (R1-T)** | Dropping resistor (CTL-007) | Ceramic. 2 ends; log any sliding tap band (R1-T) and its position. |
| **NL-BLK / NL-WHT / NL-GRN** | Neck loom (CTL-009) | The 3 motor leads at the control-unit end. GRN = LIVE branch, NOT ground. |
| **TS-#** | Terminal strip / junctions (CTL-010) | Number each lug/post of any fiber/Bakelite strip; number each free splice/twist-solder joint TSx as its own node. |
| **CHS** | Chassis (BAS-001 casting) | Reference for insulation tests + future safety-ground bond point (BAS-006 area / a stripped boss). |

- [ ] Tag count complete; **every lug in every photo carries a readable tag.**

### §2b — Contact-Point Dictation Worksheet (spoken labels) — PREFERRED METHOD
The operator's chosen method (2026-06-25): tag a contact point on **every** component, then dictate **per contact point** what lands there. This is double-entry (each wire named from both ends) and self-checking.

**Industry terminal labels** (RefDes-Terminal; tag physically + say these exact words). Locked 2026-06-25:

| Component | RefDes | Terminals (say these) | Notes |
|---|---|---|---|
| Line cord | **P1** | **P1-L** (hot/black), **P1-N** (neutral/white) | [+ P1-PE ground at rewire] |
| Rheostat (IRC) | **RV1** | **RV1-W** (wiper), **RV1-CCW** (track end) | which is wiper = meter |
| Plunger (reverse, momentary) | **S1** | **S1-COM**, **S1-NO**, **S1-NC** | count lugs; COM/NO/NC via truth table |
| Toggle (heater) | **S2** | **S2-COM** (line), **S2-NO** (load) | count lugs |
| Indicator lamp | **DS1** | **DS1-TIP** (center), **DS1-SHELL** | which wire = tip vs shell, verify |
| Heater resistor | **R1** | **R1-1 / R1-2** | non-polar end caps |
| Motor loom | **M1** | **M1-S1 / M1-S2** (field ends), **M1-A1** (green brush), **M1-A2** (internal field-tap brush) | S=series field, A=armature (NEMA) |
| Splices / posts | **TB1** | **TB1-1, TB1-2 …** | any terminal block / free splice |

**Dictation template (one per contact point, walk the whole machine):**
> "**[POINT]**: [N] wire(s) — a **[color]** [marking] to **[POINT]**; a **[color]** to **[POINT]**; … [or: one empty/unused lug]."

Rules: name **color + printed marking** for each wire; list **all** wires on a multi-wire point (catches junctions); call out **empty lugs**; saying each wire twice (both ends) is expected and good. Photograph each component **after tagging**, tags visible.

> **SUPERSEDED 2026-06-25 (same day):** the loose verbal map below was replaced by a **full contact-point trace** (operator tagged every component A/B + motor A/B/C/D and traced all 10 wires). The resolved 5-node netlist now lives in **`docs/dimensions/Control Unit Wiring Map - Sheet1.csv`** (OBSERVED conf.). Two meter items remain: **lamp voltage rating** (lamp traced PARALLEL w/ heater) and **plunger truth table**. Use the CSV as the working map; §3a kept only as the first-pass record.

## 3a. PRELIMINARY AS-DICTATED MAP (2026-06-25) — **ASSUMED, not yet metered**
First-pass connection map from the operator's verbal walk-through (`controlunit_wiring_dictation_raw.txt`) + photos. **Every row here is (ASSUMED)** until the DMM ring-out (§3/§4) confirms it. The operator flagged a **cross-connection at the resistor/lamp/plunger** he could not fully resolve by eye — treat that region as unverified.

**Confirmed functional roles (by operation):** PLUNGER **S1 = motor reverse** (out = forward, in = reverse); TOGGLE **S2 = heater switch**; GREEN motor lead → rheostat; rheostat **= IRC** brand (speed). Ceramic power resistor **R1 = the "heater unit"** — mounted in the heater well (BAS-002) on a copper strap; in series feeding the pilot lamp.

| # | From | To | Wire | Notes (ASSUMED) |
|---|---|---|---|---|
| a1 | NL-GRN (motor) | RH1 (rheostat) | green | exact lug TBD — likely wiper/speed out to motor |
| a2 | NL-BLK (motor) | S1 plunger | black | field reversing end |
| a3 | NL-WHT (motor) | S1 plunger | white | field reversing end (S1 swaps a2/a3 = reverse) |
| a4 | P1-H mains (hot) | R1 end-1 | black | mains hot into the heater resistor |
| a5 | P1-N mains (neutral) | RH1-a | white | mains neutral to rheostat terminal "a" |
| a6 | RH1-a (same lead as a5) | S2 toggle | black | branch off the neutral/rheostat node to heater switch |
| a7 | S2 toggle | R1 end-2 | black | switched leg into other end of heater resistor |
| a8 | R1 ("heater unit") | LMP1 lamp | black | resistor feeds the pilot lamp (series dropper) |
| a9 | LMP1 lamp | R1 (other side) | black | **CROSS** — operator-flagged, unresolved |
| a10 | (cross node) | S1 plunger | black | **CROSS** — operator-flagged, unresolved |

> ⚠️ The a8–a10 loop (resistor ↔ lamp ↔ plunger) is the part to ring out most carefully — verbal description was ambiguous. The DMM continuity matrix (§4) is what resolves it.

## 3. WIRE SEGMENT LIST — the directed connection map (core deliverable)
For **every physical wire/jumper**, dictate one row. This table IS the verified netlist.

**Dictation template (read aloud, one per wire):**
> "Segment S-__: from node ____ to node ____, color ____, gauge ____, insulation ____, length ____ inches, routing ____, joint type at each end (solder lug / screw / wire-nut / twist-solder) ____, confidence ____."

| Seg | From node | To node | Color | Gauge | Insul. | Length | Routing / notes | Conf. |
|---|---|---|---|---|---|---|---|---|
| S-01 | | | | | | | | |
| S-02 | | | | | | | | |
| (add rows as needed — expect ~8–14 segments) | | | | | | | | |

- [ ] Every node from §2 appears as an endpoint on **at least one** segment (orphan node = something missed — re-inspect).

## 4. CONTINUITY MATRIX — buzz every pair (catches hidden/internal links)
With DMM on continuity/ohms, **unplugged**, probe **every node against every other node** and record ~0 Ω (connected), a resistance value (connected through a component), or OL (open). This is what catches a jumper you couldn't see or a switch internally bridging two lugs.

- [ ] Fill the upper triangle of the N×N node matrix (only need each pair once). For switches/rheostat, record the reading **and the actuator position** it was taken in (see §5).
- [ ] **Insulation / isolation checks** (each should read **OL** with cord removed and switches open):
  - [ ] Every node ↔ **CHS** (chassis): expect **OL** everywhere (original design relies on isolation; any node reading short-to-chassis is a fault/hazard — flag it). (CONFIRMED/EST.)
  - [ ] NL-GRN ↔ CHS specifically: **must be OL** — proves GREEN is a live branch, **not** a chassis ground. Record the number.

## 5. COMPONENT CHARACTERIZATION — values + switch truth tables
**Rheostat (CTL-001) — RH1:**
- [ ] Identify the wiper: the lug-pair whose resistance **changes as you turn the knob** is wiper↔end; the pair that stays **fixed** is end↔end (= full coil).
- [ ] End-to-end (full coil) resistance: ______ Ω. **Target ~750 Ω (REF/NAWCC).** (CONFIRMED by meter ⇒ closes ledger **E4**.)
- [ ] Wiper sweep: full CCW ______ Ω → full CW ______ Ω; note knob direction vs ON/OFF arc; note if there's an end "click"/off detent that opens the circuit. (smooth? dead spots? open spots?)

**Dropping resistor (CTL-007) — R1:**
- [ ] End-to-end resistance: ______ Ω. **Target ~200–220 Ω, ~55 W (REF).** (CONFIRMED ⇒ closes **E4**.)
- [ ] If a tap band exists: R1-1↔R1-T ____ Ω, R1-T↔R1-2 ____ Ω, and the tap's physical position.

**Pilot lamp (CTL-005) — LMP1:**
- [ ] Cold filament resistance LMP1-A↔LMP1-B: ______ Ω (low, a few–tens of Ω = good filament; OL = burned out). Note bulb base type/markings if any.

**Plunger switch (CTL-003) — S1 truth table:** record which lug-pairs are **closed (~0 Ω)** vs **open (OL)** in each actuator state.
| State | Closed pairs | Open pairs |
|---|---|---|
| Released (rest) | | |
| Pressed (plunger in) | | |
- [ ] Determine pole/throw (SPST? SPDT? DPDT?) and whether it **swaps two lines** (= reversing) vs simply makes/breaks one (= on/off). This is the physical evidence for **E5 (plunger = reverse?)**.

**Toggle switch (CTL-004) — S2 truth table:**
| State | Closed pairs | Open pairs |
|---|---|---|
| Up / pos 1 | | |
| Down / pos 2 | | |
- [ ] Pole/throw + what it makes/breaks → evidence for **E5 (toggle = heater?)**.

## 6. NECK-LOOM (CTL-009) MAPPING — tie the two units together
- [ ] **NL-BLK** lands on node ______ (CONFIRMED). 
- [ ] **NL-WHT** lands on node ______ (CONFIRMED).
- [ ] **NL-GRN** lands on node ______ (CONFIRMED) — and **NL-GRN↔CHS = OL** re-verified.
- [ ] Cross-check against the **motor-head** map (R-11): GREEN→brush (common), BLACK/WHITE→field outer reversing ends. The control-unit terminations must be consistent with reversing via Black↔White swap (proven on the Rigol, R-10). Note any inconsistency.

## 7. BUILD THE VERIFIED SCHEMATIC — reconcile & resolve the `?` flags
- [ ] From §3 + §4, write the **verified node list / netlist** (each node → everything electrically common to it).
- [ ] Trace and confirm (or correct) the inferred **series path**: `M1(neck) → S1 → LMP1 → R1 → S2 → RH1`. Mark each hop CONFIRMED or CORRECTED with the actual segment evidence.
- [ ] Resolve the two old `?` junctions from LR-ELEC-001: **(a)** the rheostat terminal usage (which lug is line, which is wiper-out to motor); **(b)** the "Hot-ties-to-Green-rail" question. Replace `?` with metered fact.
- [ ] Reconcile against **factory diagram E-1690** (anchor): note where S/N 13505 **matches** the factory intent and where the **prior rework deviates**. Both get documented (factory intent vs as-found-this-unit).

## 8. OUTPUTS THIS FEEDS
- [ ] **`docs/dimensions/Control Unit Wiring Map - Sheet1.csv`** — the §3 segment table + §2 node registry, machine-readable. (Create from this checklist's data.)
- [ ] **Verified as-found schematic** — new SVG (supersedes the inferred LR-ELEC-001 `?` flags); CTL- part IDs on every symbol.
- [ ] **Corrected 3-wire grounded rewire target schematic** — the R-5 design: same logic, + chassis-ground bond (CHS), clip/quick-connect terminals, new 16 AWG silicone harness, modern dropping-resistor/PTC option.
- [ ] Component values (rheostat, dropping resistor, lamp) → close ledger **E4**; switch roles → close **E5**.
- [ ] Manual Part III (Restoration) electrical section + the post-rewire **cold-check continuity matrix** (already drafted in CLAUDE.md) for first power-on.

## Open questions to settle at the bench
- [ ] Lug count on RH1 / S1 / S2 (drives pole-throw interpretation).
- [ ] Is there a **terminal strip** (fiber/Bakelite) or are joints free twist-solder? (Defines how many CTL-010 nodes.)
- [ ] Does the dropping resistor mount on the **copper band/strap** (per NAWCC) — relevant to the PTC-heater replacement option?
- [ ] Any **second gasket/insulator** behind the lamp jewel or under the rheostat that should get a CTL/BAS ID?

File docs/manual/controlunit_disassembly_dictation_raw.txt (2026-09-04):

[5580 Feather Grass Ln 2 1.m4a  (344s)  — Control Unit component removal, 2026-06-25]

Continuation of the breakdown. The plunger is out — the button itself is just pressed on; give it a tug up and the button comes off, then remove the component. Next is the resistor: there's a wire band that holds it centered in the heater dwelling; a slotted screw releases tension on that band, then the resistor moves out. Screw is very rusted. Got the resistor out — there's a little paper film over it that wraps around (looks like it was adhesively backed, but it's come off); set aside. Last attached is the bulb, on a metal bracket tied to the housing — removed the bulb. The metal bracket / light piece on the main unit is attached with that same kind of bolt; crescent wrench wouldn't fit (too tight), used small pliers to grip and loosen. Removing the rheostat first actually made bulb access easier. So: bulb, plunger, resistor, rheostat all removed — **still connected to each other** (all the wiring harnesses still tied together as one cluster). Also have the little housing with a red piece — the red jewel so the bulb shows red on the unit. All components now removed from the casting.

UNKNOWN PIECE: something came off that I'm not familiar with — don't know where it came from. Looks like it might have gone out toward where the post is. Not part of any of the components. Set aside to ID later.

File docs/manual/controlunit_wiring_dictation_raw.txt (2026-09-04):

[5580 Feather Grass Ln 2.m4a  (143s)  — Control Unit wiring layout (as-observed, verbal), 2026-06-25]

Voice memo June 25th 2026. I'm just going to kind of describe the electrical wiring layout on the L&R precision watch cleaning machine. So the first part, which is the wires that go up to the motor housing unit, there is a green, white and black wire. The green wire connects to — I don't know exactly what part of the rheostat, but it connects to the rheostat. The black and white wire, they connect to the plunger, which tells the motor to go forward or reverse. When you push the plunger it goes reverse; when it's out and it's default state, it's going in a forward direction. Then there is the mains, which goes into the actual wall socket. There's only two wires that come off that: there is a white wire and a black wire. The black wire goes into one of the heater / that heater element, and then the white wire goes to the rheostat. Now if we work our way around from the rheostat where the white wire plugs in, there's a black wire coming off the same lead, and that is going to the switch that controls the heater. So that black wire goes into the switch. And then there's another black wire that feeds off that same switch into the other side of this heater unit. And then from that heater unit there's another black wire that goes all the way down to the light bulb. And then from the light bulb, there is — from that same connection — there is a black wire that crosses over to the other side of the heater unit. And then there's a black wire that goes to what looks like the plunger. So there's a little bit of a cross-connecting there. Hopefully that all made sense.

--- Visible markings in the accompanying photos (provenance) ---
- Rheostat wiper/body stamped "IRC" (International Resistance Co.) — toroidal wound coil + sweeping wiper arm.
- Inline wires print-marked "E2039x" (UL-style wire ID) — repeated on several black leads.
- Pilot lamp glass: "MADE IN U.S.A." bayonet/screw bulb in a brass socket.
- Ceramic power resistor: brown tubular body, held in the HEATER WELL by a copper strap/clamp; a wire soldered to each end cap. (= the "heater unit" the operator refers to.)

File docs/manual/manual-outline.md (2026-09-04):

# Shop Manual — Proposed Outline & Style Template
### L&R Master Watch Cleaning Machine, S/N 13505

> **REPRODUCTION DOCUMENT** — Not an original L&R Mfg. Co. technical publication. Reverse-engineered and restored by Hobbs R.E., 2026, from direct physical measurement and hands-on restoration of specimen S/N 13505. For restoration reference only.

Derived from the survey in [`reference-survey.md`](reference-survey.md). The structure follows the classic L&R two-part spine (Operate / Maintain) and **adds a third part — Restoration — which the factory manuals never had.** That restoration part is where your firsthand knowledge lives; it is the heart of this document.

## Style template (apply to every section)
- **Title block** on every page footer (per CLAUDE.md standard): Date *June 12, 2026* · L&R Precision Cleaning Machine · Master · S/N 13505 · L&R MFG. CO. · Engineer Hobbs R.E.
- **Reproduction footer** on every page (verbatim text above).
- **Section banding:** each part gets a header tab (Operate / Maintain / Restore), L&R-style.
- **Procedure format:** bold title → optional *Trouble / Cause / Remedy* triad → numbered steps → inline **CAUTION** (caps) → **Helpful Hints** bullets.
- **Every part callout uses its canonical Part ID** (UH-003, ARM-006, STR-002…) tied to the Parts Dictionary; figures are our own SVGs/photos only.
- **Dimension provenance labels** carry through: (CONFIRMED) / (EST.) / (SYN).

---

## Front Matter
- Cover — machine photo (restored), model badge, title.
- Reproduction & originality statement; how to use this manual.
- **Table of Contents.**
- **Specifications** — 110 V AC, universal series motor, 2-pole; original 2-wire (now upgraded to 3-wire grounded); overall dimensions; U.S. Patent 1872812. *(model: Tempo 400 spec habit)*
- **What's in the box / parts inventory** — original complement: basket, jars, inserts, center column, cap/gasket, cord. *(model: Console carton checklist)*

## Part I — Operating Instructions
1. Setup & leveling; jar layout (cleaning / rinse positions); fluids (period-correct vs modern safe solvents).
2. Loading the basket; basket types & inserts.
3. The controls — one at a time: **Plunger switch (S1)**, **Toggle switch (S2)**, **Rheostat speed control (RH1)**, **Pilot lamp**. Each: what it does + a CAUTION. *(model: Console "Machine Controls")*
4. Running a cycle — clean → rinse → dry/spin-off; recommendations for best results.
5. **Solvent safety** (caps warning) — modern note replacing the original gasoline/benzine/chlorinated-solvent guidance.
   - *Primary source to transcribe here: the original 4-page L&R Master operating sheet (Source 5) once a clean copy is obtained.*

## Part II — Maintenance & Service
1. **Lubrication schedule** (calendar cadence): bearings (BRG-001/002), oil-wick & feed tube (LH-006), shaft journals — lube points, intervals, **Zoom Spout oil**. *(model: Tempo 400 Periodic Maintenance)*
2. **Motor service** — brush inspection/replacement (UH-003 brush ports, UH-004 caps, UH-005 set screws), commutator (ARM-006) care.
3. **Bearing & wick overhaul** — *(promote from our completed restoration notes)*; spherical sleeve bearings, merino reservoir packing, felt washer stack, Century TA-2226CS spring.
4. **Speed-control adjustment** — rheostat. *(model: Vari-Matic "Adjusting Basket Motor Speed")*
5. **Troubleshooting table** — Problem / Solution rows: won't run (check cord, brushes, rheostat), runs slow/erratic, no spin-off, etc. *(model: Console + Tempo 400)*
6. **Diagram pages (back of section):**
   - Machine Diagram & exploded parts list → **EXP-001 / EXP-002** + Parts Dictionary.
   - **Wiring Diagram** → schematic + harness routing + **wire schedule table (W-1…W-6)**.

## Part III — Restoration (the firsthand contribution)
*Written as a restorer's narrative + reusable procedures — the part you most want to share. Model: the myretrowatches "U-seal / hydraulic" writeup, but for our subsystems.*
1. **Assessment / as-found condition** — photos, what was wrong, the green-neck-wire LIVE hazard discovery.
2. **Cosmetic refinishing** — Citristrip strip → prep/mask → IPA wipe → self-etching primer → VHT Wrinkle Plus (H/V/diagonal) → heat-cure. *(R-2 written)*
3. **Cleaning** — general mild-soap ultrasonic for small parts; Citranox on some mesh basket pieces. *(R-3 written)*
4. **Gasket conditioning** — Citranox clean + silicone-oil soak; why not WD-40.
5. **Sleeve bearing & oil-wick rebuild** — full procedure with dimensions and the felt/spring/wick stack.
6. **Electrical overhaul** *(upcoming — the next active work):*
   - As-found verified schematic (ring-out with DMM).
   - 3-wire grounded rewire: cordage, chassis ground bond, silicone wire spec.
   - **Wire harness BOM (W-1…W-6)** + pre-cut/tin bench prep.
   - **Cold-check diagnostic matrix** (ground continuity, hot/neutral-chassis shorts, circuit continuity) before first power-on.
7. **Reassembly** — motor housing reinstallation (the designated "first procedure to fully document"): tools, techniques, step sequence, torque/fit notes.

## Appendices
- **A. Parts Dictionary / BOM** — canonical Part IDs + names (+ any known original L&R part numbers cross-referenced from the 1995 list).
- **B. Confirmed dimensional dataset** — the 5 CSVs.
- **C. Drawing index** — the 9-sheet SVG package.
- **D. Materials & consumables** — paint, solvents, oil, wick/felt, spring, cordage, wire.
- **E. References & attribution** — the surveyed L&R manuals (Vari-Matic, Tempo 400, Console, U-seal sheet) and forum/archive links, cited as influences. No reproduced figures.

---

## Build order (suggested)
1. Lock this outline with the user.
2. Draft **Part III (Restoration)** first — it's mostly written already inside CLAUDE.md and it's the unique value. Convert each COMPLETE phase into a formatted procedure.
3. Slot in **Part II** (maintenance/troubleshooting/diagrams) — reuses existing drawings + harness BOM.
4. Draft **Part I** once the original Master operating sheet (Source 5) is obtained for accurate primary content.
5. Decide output format (Markdown source → PDF/`docx` for distribution) and the repo LICENSE before publishing.

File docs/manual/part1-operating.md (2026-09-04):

# Part I — Operating Instructions
### L&R Master Watch Cleaning Machine · Master · S/N 13505

> **REPRODUCTION DOCUMENT** — Not an original L&R Mfg. Co. technical publication. Reverse-engineered from specimen S/N 13505 by Hobbs R.E., 2026. For reference only.

*Title block: Date June 12, 2026 · L&R Precision Cleaning Machine · Master · S/N 13505 · L&R MFG. CO. · Engineer Hobbs R.E.*

> ⚠️ **Best-judgment procedure.** No original L&R Master operating sheet was available for this specimen. The operating sequence below is **reconstructed** from the machine's mechanism, its controls, and general watch-cleaning practice — it is not factory-verified. Treat it as a sound starting point, not gospel.

---

## I.0 — What the machine does

The L&R Master is a **spinning-basket parts cleaner** for watch and clock movements. A motor drives a mesh **basket (BSK-002)** that holds the disassembled parts. The basket is lowered into a jar of cleaning or rinsing solution and spun (in both directions) so the fluid scrubs the parts; it is then moved to the next jar, and finally to a heated **drying chamber**. The motor head rides on a swiveling carrier so the operator can index the basket over each station in turn.

**Stations (4 wells, 2×2 grid):**
- **3 solution jar bays (BAS-003)** — glass jars of cleaning fluid, then rinse(s).
- **1 heater well (BAS-002)** — a tall tube that acts as a warm-air **drying chamber** (the heating element R1 sits below; the basket parks above it, never touching it).

---

## I.1 — Controls

| Control | Part | Function |
|---|---|---|
| **Speed knob** (front, center of tongue) | Rheostat CTL-001 | Motor speed **and ON/OFF**. Full counter-clockwise = OFF. There is no separate power switch. |
| **Plunger button** (top of tongue) | Plunger switch CTL-003 | **Momentary REVERSE.** Released (out) = forward; press and hold = reverse. |
| **Toggle** (left side face) | Toggle switch CTL-004 | **Heater ON/OFF** (also lights the pilot). |
| **Red jewel** (upper-left of tongue) | Pilot lamp CTL-005/006 | Lights when the **heater is on**. |
| **Speed carrier** (rides the post) | Carrier NCK-002 | Swivels/locks to position the basket over each well; the clamp handle (NCK-003) raises/holds the motor. |

---

## I.2 — Setup

1. **Place the machine on a GFCI-protected outlet** on a stable, ventilated bench. (See Safety, I.4.)
2. **Fill the jars:** put your cleaning solution in the first jar bay and rinse solution(s) in the others, per your chosen watch-cleaning fluids. Seat each glass jar in a bay. The tapered rubber seal (PLT-002) on the platform deck wedges into the jar mouth to contain splashing.
   > ⚠️ **Use non-flammable / water-based solutions** — the motor sparks at the commutator (see I.4).
3. **Load the basket:** place the disassembled parts in the mesh basket (BSK-002); use the multi-movement holder inserts if cleaning several movements. Close the lid. Mount the basket on the drive spindle (SPN-002).
4. **Check the speed knob is at OFF** before plugging in.

---

## I.3 — Cleaning cycle (typical)

1. **Index over the first jar.** Swivel the carrier so the basket is centered over the cleaning jar, and lower it in.
2. **Start slow.** Plug in, then **sweep the speed knob up from OFF** to start the motor and set a moderate speed. (Starting from OFF is a soft-start — see I.4.)
3. **Agitate both directions.** Let it run forward, and **press-and-hold the plunger** periodically to reverse — alternating directions helps the fluid work through the parts. Run for your preferred cleaning time.
4. **Return to OFF, raise, and move to the next jar** (rinse). Repeat the spin/reverse agitation.
5. **Repeat through the remaining rinse jar(s).**
6. **Dry.** Index the basket over the **heater well**, switch the **toggle ON** (the red jewel lights), and spin the basket in the warm chamber to dry the parts. Give it enough time to dry fully, then switch the heater OFF.
7. **Shut down.** Return the speed knob to **OFF**, **then unplug.** Remove the basket and retrieve the parts.

---

## I.4 — Operating safety (read before use)

- **Non-flammable solutions only.** The motor is a brushed universal motor and **sparks at the commutator** — a normal ignition source. Never run it with volatile/flammable solvent vapor around it. Use water-based or non-flammable cleaning fluids and keep the area ventilated.
- **Keep it on a GFCI.** Liquids next to a mains motor is exactly the shock scenario a GFCI protects against. The machine is earth-grounded (restoration upgrade), which makes the GFCI fully effective.
- **Soft-start habit:** always have the **speed knob at OFF when you plug in and unplug**, and start the motor by sweeping the knob up. This avoids an inrush surge/spark and is gentler on the motor and brushes.
- **Don't force a seized basket or carrier** — free gently.
- **Hot chamber:** the heater well and dried parts are warm — handle accordingly.
- **The machine is live whenever plugged in** (the speed knob is the only on/off) — unplug it when not in use.

---
*Figures: control layout — `drawings/` base-casting plan (LR-BASE-001) + `photos/control-unit/`. Wiring — `drawings/electrical/LR-ELEC-003`.*

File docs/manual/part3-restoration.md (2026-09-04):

# Part III — Restoration
### L&R Master Watch Cleaning Machine · Master · S/N 13505

> **REPRODUCTION DOCUMENT** — Not an original L&R Mfg. Co. technical publication. Reverse-engineered and restored by Hobbs R.E., 2026, from direct physical work on specimen S/N 13505. For restoration reference only.

*Title block: Date June 12, 2026 · L&R Precision Cleaning Machine · Master · S/N 13505 · L&R MFG. CO. · Engineer Hobbs R.E.*

**About this part.** The original L&R manuals covered only *operation* and *maintenance*. This part documents what they never did — how to **restore** a seized, decades-old machine: assess it, take it apart without damage, recondition the parts, reassemble it, rewire it to modern safety standards, and bring it back to life. Procedures use canonical Part IDs (e.g. ARM-010, FLG-002) from the Parts Dictionary; dimensions carry their confidence label. Figures reference the project's bench photos (`photos/`) and engineering drawings (`drawings/`). Full as-performed detail — every product, tool, and caution — lives in the source logs (`restoration-log.md`, `teardown-log.md`); this chapter is the curated, readable version.

**Restoration philosophy.** Mechanical and visible parts were restored toward original appearance and function. The **electrical system was deliberately modernized** for safety and serviceability — the original was a 2-wire ungrounded design with a live "green" wire and no earth ground, and this specimen had prior amateur rework. Every deviation from original is documented so the record stays honest.

---

## III.0 — Assessment (as-found)

Document the machine's condition before touching it — it drives every later decision.

**Mechanical.** The motor housings (UH-001 / LH-001) carried decades of baked-on factory enamel, oil varnish, and grease crosslinked into the porous aluminum. The self-aligning spherical sleeve bearings (BRG-001 / BRG-002) were mechanically sound and reusable, but their **consumables were spent** — the wool-felt washers were brittle and broke apart on disassembly, and the reservoir yarn was bone-dry. The tapered rubber jar seal (PLT-002) was dried and near-degraded. Several parts had seized from age and required gentle freeing (never force).

**Electrical — the critical hazard.** The neck loom carries three wires (black / white / **green**). **The green wire is NOT a safety ground — it is a live, current-carrying motor branch.** Treat all three neck conductors as hot. The machine had no earth ground, and inspection showed **prior amateur rework** (nasty solder blobs, one switch contact failed on a bad joint, a non-original bulb). This confirmed the electrical system should be rebuilt rather than preserved.

**Previously modified / non-original.** Gasket-to-disk rivets (PLT-005) had to be drilled out to service the seal; the pilot bulb was a later replacement; the AC cord grommet had disintegrated.

*Fig. III-0: machine as-received — `photos/` (overall) + reference S/N 13645.*

---

## III.1 — Disassembly

Performed in the order below; reassembly (III.3) is essentially this in reverse. *Terminology note: where a prior bench recording said "stator/stator shaft" it meant the **armature/rotor**; "field coil" meant the **stator (STR-001)**. This text uses the canonical terms.*

### III.1.1 — Remove the basket and drive spindle
The basket and its drive spindle come off the motor as one "outer column." A single **set screw (SPN-005, ¼-20, slotted)** locks the basket drive spindle (**SPN-002**) to the armature's lower journal (**SHF-003**). Back the set screw out with a flat blade, then draw the spindle/basket assembly off the shaft. If seized from age, free it with **very light, deliberate taps of a rubber mallet** — gentle pressure only, never a hard strike.
*Fig. III-1: `drawings/components/SPN-002…`, `BSK-002…`.*

### III.1.2 — Understand the platform deck (before the housing bolts)
Beneath the motor is the jar-seal deck: a flat metal **platform disk (PLT-001)** carrying the tapered rubber **jar seal (PLT-002)**. The gasket is fixed to the disk by four **rivets (PLT-005)**; the remaining two holes pass the long **housing bolts (FLG-002)** — through **standoff tubes (PLT-004)** — which clamp the two motor-housing halves together. Knowing this prevents surprise when the next step releases several parts at once.
*Fig. III-2: `drawings/components/PLT-001…` + `photos/gasket/`.*

### III.1.3 — Separate the housings
Unscrew the **two long housing bolts (FLG-002)**. The lower housing (**LH-001**) drops away, and the **armature (ARM-001)** comes down with it (the rotor stays seated in the lower bearing, BRG-002). Support the dropping assembly so the commutator and windings are not knocked.
*Fig. III-3: bolt circle 2.300" — `drawings/exploded/EXP-001…`.*

### III.1.4 — Remove the lower thrust ring (ARM-010)
A stepped brass slinger/thrust washer (**ARM-010**) remains on the lower journal, just outside the housing face; it must come off before the armature will withdraw. **Do not pry it** — the ring is brass and bends easily. Instead, clamp the housing in a vise **raised on blocks** so the shaft hangs clear, tap the **top** of the shaft squarely with a rubber mallet to walk the ring a short way down the journal, then seat a small **gear/bearing puller** behind it and draw it off evenly.
> **CAUTION — keep all force axial.** Uneven pull or prying will distort the brass ring.
*Fig. III-4: `photos/bearings/`.*

### III.1.5 — Disconnect the electrical
A three-wire loom (black/white/green) runs from the control unit into the motor and lands on the **stator field coil (STR-001)**. Cut these leads at the coil to free the motor. On reassembly they are **replaced**, not re-spliced.
> **CAUTION — the GREEN wire is LIVE, not ground.** Treat all three as hot.
*Fig. III-5: `photos/stator-wiring/`.*

### III.1.6 — Remove the stator (field coil)
Remove the **two stator mount screws (STR-008)** and lift the field coil (**STR-001**) out of the upper housing. (The yoke's other two holes were the FLG-002 pass-throughs, already out.)
*Fig. III-6: `drawings/components/STR-001…`.*

### III.1.7 — Remove the sleeve bearings and springs
Each housing retains a self-aligning spherical sleeve bearing (**BRG-001** upper / **BRG-002** lower) held by a conical spring (**BRG-012**). *As performed:* face-down on a rubber/wood block, the bearing was tapped out of the spring, then the spring removed. This worked but may not be ideal — a better technique is an open question for this design.
> **Recommended candidates (untested here):** (1) release the conical spring first — it captures the ball; (2) warm the aluminum housing (~80–120 °C) to open the fit; (3) press (not hammer) with a drift on an open-bore fixture; (4) soft drift / blind-hole puller. Keep force axial; never pry the spherical socket.
*Fig. III-7: `drawings/components/BRG-001…`.*

**End state:** motor fully disassembled, all internals out, ready for cleaning and refinishing.

---

## III.2 — Component restoration

### III.2.1 — General cleaning & degrease (R-3)
As each sub-assembly came apart, small hardware (bearings, fasteners, collars, washers, the oil feed tube LH-006, small brackets) was degreased in an **ultrasonic tank with a diluted mild-soap solution**, then rinsed and dried. Mild/neutral chemistry was chosen deliberately — safe across the mixed materials (steel, brass, aluminum, phenolic). Oversized parts (housings, base casting, neck/pillar) were **cleaned by hand**. Some mesh basket pieces (BSK-002) carried baked-on chemical sludge and got a stronger **Citranox** clean.
> **CAUTIONS:** ultrasonic degreasing **strips all lubrication** — bearings must be re-oiled before/at reassembly (III.3); **dry parts promptly** (bare steel/aluminum flash-rusts); keep the chemistry mild.

### III.2.2 — Jar-seal gasket reconditioning (R-1)
The tapered rubber jar seal (**PLT-002**, molded with the maker's mark *U.S. PATENT 1,872,812*) was dried, stiff, and brittle. Restore it by: (1) a warm **Citranox** clean to remove the orange-brown chemical film; (2) a **16+ hour immersion soak in 100% silicone oil** (SEKODAY, a non-cracking silicone sold as treadmill-belt lubricant) to fully re-saturate the rubber; (3) a microfiber buff to a satin-black finish. Result: pliability fully restored, structurally sound again.
> **CAUTION — silicone only on rubber.** **WD-40 / petroleum distillates are ruled out** — they swell and degrade vintage elastomers.

### III.2.3 — Platform-deck refastening (R-6)
The gasket (PLT-002) was originally **riveted** to the platform disk (PLT-001) by four rivets (PLT-005), which had to be drilled out to service it. Restoration substitutes a **serviceable screw set**: per hole (×4), a **stainless M4-0.7 × 10 mm flat-head Phillips screw + hex nut**, reusing the **original flat washers (PLT-006)**. The countersunk head sits flush. The gasket is now removable for future service.
> *Drawings show the original rivet as the design of record, with a note citing this restoration substitution.*

### III.2.4 — Bearing-system materials (R-4)
The **bearings themselves (BRG-001/002) and the conical springs (BRG-012) were sound and reused** (cleaned per III.2.1). Only the spent consumables were replaced, mirroring the original wick/felt oiling scheme:
- **Reservoir yarn (BRG-008):** Estako Wool 98 — 100% Superwash Merino, **un-dyed** (won't leach dye or mat when oil-saturated).
- **Felt washers (BRG-009 large / BRG-010 small):** SAE F3 hard wool felt (dust block + oil containment).
- **Oil wick:** GE 1/8" vintage-fan wick (~1¼"), tied to the yarn.
- **Oil:** Bramec Zoom Spout turbine oil.

*(The Century Spring TA-2226CS was identified as the dimensional equivalent for BRG-012 if a spring is ever needed, but the originals were reused.)*

### III.2.5 — Motor-housing cosmetic refinishing (R-2)
Both housing halves (UH-001 / LH-001) carried crosslinked baked-on factory finish. Refinish sequence:
1. **Chemical strip:** coat with **Citristrip** gel (citrus-based, safe on aluminum), dwell, and work the softened finish out of the deep fins, chambers, and notches with brushes/picks. **Remove all residue and dry immediately** (bare aluminum flash-rusts).
2. **Prep & mask:** lightly scuff the exterior for primer tooth; precision-mask every running face, bore, and mating flange (FLG-001) with razor-trimmed high-temp tape.
3. **Final wipe + etch primer:** wipe with **99.9% IPA**, then **Rust-Oleum 249322 self-etching primer** in ultra-thin coats (matte olive-grey = proper anchor).
4. **VHT Wrinkle Plus topcoat:** 3 heavy crosshatched coats — **horizontal → vertical (5-min flash) → diagonal (5-min flash)** — a wrinkle finish needs a thick film with tight flash times to ripple.
5. **Thermal cure:** draw the texture with controlled heat (**~350 °F** heat gun and/or oven after the level window). **Pull the masking while the film is still warm** to preserve internal dimensions.

Result: tight, uniform heavy wrinkle grain matching the vintage L&R aesthetic, tolerances preserved.

### III.2.6 — Control-unit / base-casting refinishing
The cast-aluminum base body was stripped (Citristrip), and worn cast lettering ("OFF" on the tongue, the "L&R MASTER" relief) was rebuilt with **J-B Weld High Heat epoxy** on abraded bare metal (it survives the ~350 °F wrinkle bake, unlike polyester filler), then block-sanded flush and the lettering re-cut with a Dremel. The same **etch primer → VHT Wrinkle Plus** system as the housings was applied, inside and out, for a matching texture.
- **Cast lettering was left monochrome** (shot with the wrinkle, no color fill) — factory-correct, the relief reads by shadow.
- **Cure without an oven:** heat-gun draw to form the wrinkle, then a multi-hour cure in direct sun + a warm garage (48–72 hr undisturbed). Confirmed workable.
- **Chrome parts** (post NCK-001, clamp screw NCK-003) were cleaned and sent out for professional **re-chrome**.
> **CAUTION — bake-proof masking.** Ordinary painter's tape (~250 °F) scorches at the wrinkle bake; swap to high-temp masks (silicone plugs / stainless bolts / Kapton) before the topcoat. Keep fit surfaces (the BAS-006 post socket, screw holes) masked so wrinkle texture doesn't spoil the fit.

---

## III.3 — Reassembly

### III.3.1 — Bearings & lubrication, lower housing (R-7)
*No public instructions exist for this — the method reconstructs the original wick/felt capillary oiling.*
1. Cut ~1 ft of wool yarn (BRG-008) and ~1¼" of GE wick; **tie them together**.
2. **Route the yarn through the oil-wick port** — stiffen the floppy lead with a wrap of Scotch tape and pull it through with tweezers.
3. Place the **small felt (BRG-010) flush at the bottom of the bearing** (it contacts the incoming wick = how the lower felt gets oiled); route the yarn **up the side**, wrapping the **large felt (BRG-009)** at the top neck (oil wicks up to the upper felt).
4. **Seat the bearing (BRG-002)** — mind the **bottom notch** (one orientation only).
5. **Pre-oil** the felts + yarn with Zoom Spout; let it soak.
6. Insert the **conical spring (BRG-012)**.
7. Install the **retaining ring (BRG-011)** at the bottom (friction fit) — tap flush with a **brass punch + light rubber-mallet** taps, working evenly around.
8. Clean the bore (alcohol pads); **test-fit the armature** (good).
> **CAUTION — no steel tools under pressure.** Use brass punches; light, even, axial force only.

### III.3.2 — Bearings & lubrication, upper housing (R-8)
The harder of the two (15+ attempts). Key differences: the upper bearing (**BRG-001**) has an **internal slit** and the yarn rides **inside** it; the upper "small felt" is a **solid tab/pad** (pin-hole only) that sits at the very top under the **oil cap (UH-011)**; and there is **no bottom retaining ring**.
- **Working method:** tie the yarn around a small **~0.400" wood peg** with a hitch knot, slip that over the bearing's inner end, route the other end **through the internal slit**, wrap it tight at the top, and **anchor the terminal end with a dab of super glue** (the pliable felt detaches during seating otherwise). Thread the lead up through a poked hole in the top felt pad; seat the bearing; add the large felt; pre-oil; insert the spring; test-fit (spins fine); cap the oil port.
> **Open item (VERIFY):** the super-glue anchor's effect on long-term wicking is unknown — watch oil feed over time. It was a last resort with no manual to reference.

### III.3.3 — Armature + slinger, mechanical assembly (R-9 → R-11)
1. **Phenolic end-float washers:** stack the 4 washers on the lower journal — **ARM-012 (small) against the bearing, then ARM-011 ×3**. (These set the rotor's axial position so the fan clears the housing floor. A matching set, **ARM-013 ×4**, goes on the upper journal at final join.)
2. Set the lower housing onto the armature so the journal passes through BRG-002; invert into a press.
3. **Press the slinger (ARM-010) onto the journal with slow incremental axial pressure — do NOT bottom it out.** Leave a running gap ≈ **0.0255"** (a knife-blade width); gauge with a feeler as you go.
   - *Tool:* a bench **arbor press** with a **tubular driver / deep socket / fender washer** whose bore clears the shaft and whose face bears on the slinger. **Never hammer.** (The restorer improvised with a reloading press + a 3/8"×1¼" fender washer; the principle is the same.)
4. **Join the housings:** install the stator (STR-001, two STR-008 screws), drop the armature in from the top, fit the ARM-013 ×4 upper washers against BRG-001, and torque the **two FLG-002 tie-bolts** (which also clamp the platform deck via the PLT-004 tubes).
5. **Deck → spindle → basket:** platform deck (PLT-001/002) → basket drive spindle (SPN-002, SPN-005 set screw) → mesh basket (BSK-002) bayonets on + lid → brushes (UH-004 caps) → oil cap → mount to the body.

### III.3.4 — Electrical: modern grounded rewire (R-5)
The control unit was rewired to a **modern, safe, serviceable standard** per the restoration philosophy. The as-found circuit was meter-verified into a 6-node map (see `LR-ELEC-002`), and the rebuild follows the corrected grounded schematic **`LR-ELEC-003`**.
- **Wire:** 18 AWG silicone (200 °C) throughout; a new **3-conductor grounded cord** with NEMA 5-15P plug.
- **Color code:** BLACK = hot, WHITE = neutral, **GREEN = ground only**, RED = motor forward, BLUE = motor reverse, YELLOW = motor speed/common, **RED-with-band** = heater/lamp return.
- **Junctions:** **Wago 221 lever connectors** at the distribution nodes (hot 5-port, neutral 3-port, return 3-port); motor legs on serviceable 2-wire joins; component leads on crimp/heat-shrink terminals. The **rheostat's two solder lugs** are the only soldered joints.
- **Ground bond (W-6):** green ring lug under a star washer to bright bare aluminum on the casting.
- **Switches:** the failed plunger (S1) and frayed toggle (S2) were replaced (same node roles).
> **CAUTION — the motor loom's green lead is a LIVE common, not ground.** Band it red at its junction so green never reads as ground in this machine.

### III.3.5 — Motor-lead entry: grommet, sheath anchor, strain relief
The four motor leads leave the sealed motor head and drop down the chrome pillar into the casting, where they pass a **bare aluminum edge at the housing/base entry**. This is a hard-earned lesson, not an optional nicety:

> **FIELD-FAILURE LESSON (specimen 13505).** During routing, the protective sheath over the motor leads slipped back at the housing entry and left a short length of the **WHITE lead bare**. That bare conductor touched the grounded aluminum base and **arced** on power-up. The ground system did exactly its job — the fault went line-to-ground and cleared, never energizing the chassis — but the lead had to be rebuilt. Root cause was purely mechanical: an unanchored sheath and no strain relief let the insulation migrate.

**Do this at the motor-lead entry, every time:**
1. **Grommet the pass-through.** Fit a rubber grommet (or high-temp silicone) in the entry opening so no conductor ever bears on a bare cast edge.
2. **Anchor the sheath.** Fix the protective sleeve so it **cannot slide back** off the conductors — a cable clamp, tie anchor, or adhesive-lined heat-shrink at the entry. The sheath must stay put under the pillar's routing tension.
3. **Add strain relief.** Secure the loom just inside the entry so any pull is taken by the jacket, not by the solder/crimp joints or the insulation at the edge.
4. **Re-inspect before closing up.** With the leads dressed, confirm no copper is visible anywhere along the run and that flexing the loom does not expose any.

---

## III.4 — Commissioning (cold-check & first power-on)

Never apply mains until the machine passes an unpowered cold-check.

**Stage 0 — cold checks (cord unplugged, DMM). All must pass:**
1. Ground pin ↔ bare chassis: **≤ 0.2 Ω** (near-zero over lead resistance).
2. Hot ↔ chassis, Neutral ↔ chassis, Ground ↔ hot, Ground ↔ neutral: all **O.L. (open)**.
3. Branch continuity: all-off = O.L.; rheostat on = motor winding + rheostat (tens–hundreds Ω, dropping as the knob advances); toggle on = **≈ 220 Ω** (heater R1 in parallel with the pilot lamp).

*As performed, Stage 0 caught and fixed two real faults — a marginally-seated Wago (added ~60 Ω series resistance) and a dead pilot bulb — which is exactly its purpose.*

**Stage 1 — first power-on.** The safest first power-up is through a current-limiting **dim-bulb tester + GFCI**; with Stage 0 fully passed and the motor already proven on a low-voltage DC bench supply, a direct power-on is a reasonable low-risk alternative. **Always start with the rheostat at OFF** (it is the motor's only on/off), plug in, then sweep the speed up (a soft-start that spares the plug, brushes, and commutator); return to OFF before unplugging.

**Result (S/N 13505):** motor runs and reverses cleanly, rheostat controls speed, heater warms the drying chamber (~160–200 °F), pilot lamp lit. Full function confirmed.

> **OPERATING SAFETY.** (1) The commutator sparks (normal for a brushed motor) — an ignition source — so **use non-flammable / water-based cleaning solutions and good ventilation**, never volatile solvent near the running motor. (2) Because the machine handles **liquids next to a mains motor, keep it on a GFCI** for all use.

---
*Figures to be finalized from `photos/` and `drawings/`. Confidence labels per the Document Production Standards. Full as-performed detail (products, provenance, per-photo figure notes) in `restoration-log.md`.*

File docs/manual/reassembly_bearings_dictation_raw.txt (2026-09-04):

[5580 Feather Grass Ln 2.m4a  (200s)]
Okay, so this is a race memo, it's June 19th, 2026, and I am recording the reassembly of the lower housing, starting with the lower housing, bearing. So currently I have the parts in front of me, I have the lower housing. I have the spring that the bearing fits into, I have two brand new SAE F3 felt washers, one of them is a smaller washer, one of them is larger washer, they go around the bearing. I have a metal retaining washer that goes at the very, very end, and then I have of course the bearing itself, and then I purchased 1.8 inch diameter GE, an old GE oil wick for fans, for old fans. And so what I'm going to try to do now is based, when I took this apart, the washers, the old washers were kind of brittle and broke apart, and then there was what looked like wool felt string wrapped around the bearings. I'm having to deconstruct this, this is based on just kind of assumptions, but my understanding is with this 1.8 inch wool wick, I'm going to wrap wool yarn around it tightly, and then I'm going to feed that through and wrap it around the smaller washer, and then feed that same wool yarn up to the larger washer and wrap that around, and then basically insert the bearing, and then the bearing is notched at the bottom, so the bearing can only go in one way, and it has to basically fit into that notch. Once the bearing is in place, and that is basically in place with all of the oil felt wicks routed around it, the lower washer, the yarn, and the upper larger washer, I will then insert the tension spring into the housing, and that should complete the assembly, the reassembly of the lower housing bearing. So I will stop here and start to work on that, and then update voice memos with any updates or progress.

[5580 Feather Grass Ln 3.m4a  (40s)]
Okay, so I have cut a piece of wool yarn about one foot long and I have cut about an inch and a quarter of the oil wick. So the next step that I'm going to do is I'm going to tie the yarn around the wick so that I can route it through the oil wick hole and into the felt washers, and then assemble the actual bearing with all the felt washers. So I'm going to start that now and then I'll update here later.

[5580 Feather Grass Ln 4.m4a  (134s)]
Okay The wool yarn Tie it around the oil wick and I'm beginning to route it through the oil wick port now the wool yarn is It's not it's not sturdy. So as soon as you try to insert it into the oil wick port, it's very difficult to route it So what I did is I took just a tiny bit of scotch tape on the end that I'm gonna route through the oil wick And just wrapped it around to give it a little bit of sturdiness So it's easier to insert it into the oil wick port and then I took my tweezers and just Slowly grabbed on to that and pulled it through and it's allowing me to route everything through the hole properly and now the next step that I'm going to do is I'm going to attach the lower washer to this wool yarn and then put that lower washer on the bottom part of the bearing and then I'm going to continue to route the yarn up and attach it to the larger felt washer and then tie that off properly and put the felt the larger felt washer on top of the bearing and Then insert it as one unit into the Into the housing and make sure everything fits properly The next thing that I will do is I'll Take it out because I'm just going to test it. I'll take it out and then I'm going to use this bramec zoom spout oiler It's a multi-purpose turbine oil I'm going to basically pre lubricate the the The felt washers and make sure they have oil and also the felt yarn just to make sure everything has oil When it's ready to go So I will do that and then I will update on another voice memo

[5580 Feather Grass Ln 5.m4a  (197s)]
Okay. So, kind of a little bit of a rearrangement here. Here's what I did. I tied the yarn to the oil wick, put that in there, but the lower washer actually sits more flush to the bottom, so it's not, the yarn is wrapped around it. It sits flush at the end of the bearing towards the bottom. So, I have some pictures of that. So, it's just sitting there flush, the small little washer, and then the yarn is wrapped up and goes up along the side of the bearing, and then I have the larger washer sitting on top, and the yarn is wrapped around the top neck of the bearing with the larger washer. So, I guess the premise here is the oil will wick through, and that capillary action will soak up the oil in all these various parts. We'll see. I think what I will do is I will put some plastic down here and then oil up these parts and just kind of let it sit for a bit and kind of see how it works. I'll do that, and hopefully that all works and all this stuff is good. I have no idea what I'm doing here. I'm kind of just winging it, and I don't think there's any, there's no public instructions on this. So, just to recap, I have a 1 eighth oil wick that's used for old fans, like old 1920s, 1930s fans. I cut about an inch and a quarter of that. I tied my wool yarn to it and some pretty tight knots, routed the yarn through the oil wick port. I put the smaller washer flush with the bottom of the bearing, and then I routed the wool yarn up the side of the bearing, wrapped it, met it with the larger felt washer, and then wrapped that yarn around in concentric circles around the top neck of the bearing. Now I'm going to pre-lubricate everything with the oil. Let that sit for a bit, and then the last step is I'm going to install the tension spring, and then hopefully that's it. That's everything for what we need to do here, at least as far as reinstalling the bearing in the lower housing unit.

[5580 Feather Grass Ln 6.m4a  (245s)]
So I have the bearings installed on the lower, the bearing installed on the lower housing unit. So this was quite tricky actually. So our original task of getting the wool yarn routed through the cavity, the oil wick, wrapping it around the bearing, that all still holds true. It is true that the smaller felt washer just sits at the bottom of the bearing and that makes contact a little bit with the oil wick, or at least the portion of the wick that's coming in. So that's how that part gets oiled. And then obviously the oil from the wick that is running on the yarn gets up into the larger felt and that's how that larger felt remains oiled. So I'm not exactly sure, like obviously this is an older piece of machinery, I'm not sure how effective that really is, that capillary action versus like a traditional bearing, like a roller bearing type setup which is on the mark two versions of these units. These are very old. Mark one versions. So it's a little bit more, you know, archaic I guess. Then there was one part that I did not capture. There is a metal, it almost looks like a washer, but it's a retainer ring that sits at the very bottom of the housing. This covers the felt washer and it retains everything, you know, make sure that that doesn't like slip out. So that outer diameter is 0.500 inches. The interior diameter is 0.295 inches and the thickness is 1 16th of an inch. So that's a new part that we need to add into our diagram. But everything else is looking good. So yeah, the lower housing, I did a test fit with the armature and it fit fine. One last thing that I did is I wiped everything down and I used alcohol prep pads to basically wipe down the bore of the bearing to clean that out to make sure that's clear and free of any debris from when we were installing the felt and the bearings and things like that is when to make sure it's really nice and clean. The other part of the tools that's really necessary here is do not use steel parts. Do not use like steel tools, like steel tweezers are okay if you're inserting something but do not put any pressure on anything because that will mar the bearing, it will mar the housing. So what I did specifically on that little retainer washer that sits at the bottom, that new part, is I used brass flat punches to help me kind of tap down very slow. I did not use a lot of force, I basically used the Gracie USA brass punches and what I did is I took a rubber mallet and just very tightly tapped it down evenly on all around the retainer ring in order to secure it so that it sits in the housing flush. Yeah, so with the brass it's a soft metal so it's not going to mar it. And yeah, so that's pretty much it.

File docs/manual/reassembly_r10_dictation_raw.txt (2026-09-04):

[5580 Feather Grass Ln.m4a  (86s)]
I'm just going to voice dictate what you're doing here. As far as the electrical goes in the upper housing, there's wires of various length. So for instance, the green wire, which is going to have the clip, that's going to be a much longer wire than the black or the white wire. So to give me adequate working space, I've cut the sheath about 5 and 1 by 2 inches back from the three-wire plug. My hope is that that will give me enough room to put my shrink wrap tubing on so I can cover my solder points. And hopefully, that gives me enough play in there where I can push the wires back. And then I'll put the larger heat shrink wire loom, the nylon wire loom, around everything and run that. And that will go basically down to the main unit. I don't know if this is going to work. So probably what I'm going to do is do some test fittings. I might have to do a few runs of this before I get it right. So I guess we will see how that works.

[5580 Feather Grass Ln 2.m4a  (105s)]
So for the green wire, I put a red heat shrink tubing over it to signify that it's hot. For the black and white wires, it's a black and white heat shrink tubing. I pulled back from the 3-wire 16-gauge, I pulled back about 5.5 inches, stripped that off. Then because there's varying links inside the actual housing, I have the green wire sitting at five and a half inches and I'm probably going to snip it to about four and a half and then solder the clip onto it. And then the black and white wires, I've cut those back to about three and a quarter a piece. And I'll snip, I'll basically splice those onto the existing wires, solder them and then all three of them I'll put the heat shrink tubing on. And then I have a larger black heat shrink tubing around the 16-gauge that I will pull up and surround those open exposed wires entirely so that they're not showing.

[5580 Feather Grass Ln 3.m4a  (35s)]
To do the wiring installation, I've removed the stator from the upper housing, that way that will give me clearance and when I start to do the actual wiring, I will route the 16 gauge through the port on the upper housing and then connect it into the stator and then feed the stator back into the housing and back out the wire as needed. This way, I have a little bit more room to do the soldering instead of trying to do it while it's in the housing.

[5580 Feather Grass Ln 4.m4a  (248s)]
Okay, I've got my solder station set up. I basically have the brass clip rolled by some alligator first, and another alligator clip holding the green wire, which is our hot. And essentially what I'm going to do is I'm going to put a little bit of flux on the connection, and then apply some solder, just gently. Just to kind of get that, I got the soldering iron tip, uh, tinned. So that should be good. Um, hopefully this all works. So I'm just going to keep this on while I'm dictating. So I'm applying a little bit of tacky flux to the actual where our connection's going to be. I'm just applying that generally liberally around, and then I have my solder, lead-free solder. I'm just going to touch this. Okay, it's working. And now I'm just going to go ahead and apply the solder to the joint. Actually, to be honest with you, I'm going to change up how I'm doing this. That is not the best solder connection I've done. Look at this again. Put a little bit more flux on the joint, get a more solid connection. Basically, I'm trying to make a solder pad, and then put the wire on it, is what I'm trying to do here. Okay. So I have what I think is a good connection. Let me just double-check it. Okay. This should be a good connection. It's a good solder connection. Okay. I'm going to put the heat shrink tubing around it. Okay. The heat shrink tubing is around it. And now I'm going to apply heat to shrink the tubing.

[5580 Feather Grass Ln 5.m4a  (35s)]
So actually what I've done is So I put the the clip on for the red hot wire I have not actually shrunk the heat shrink tubing over it yet but I'm actually going to do is I'm going to put everything back with the stator and I'm going to hastily rewire so just using some electrical tape wire the connections and Then I want to actually run my electrical test before I do any soldering So that's where I'm going right now

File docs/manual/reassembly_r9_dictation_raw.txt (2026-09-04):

[5580 Feather Grass Ln.m4a  (159s)]
Okay, it's June 21st, 2026, Father's Day. I am now getting prepared to seat that slinger bearing into the lower housing shaft. So what I've done is I've kind of improvised a solution here for how I could potentially get even pressure to mount this. It's kind of very similar to a bearing press, but what I'm using is my ammo reloader, a Dillon XL650. I basically have the platform kind of empty right now, and the plan is I set the lower housing upside down with the armature in there, everything kind of assembled. I will set the ring washer on top, and then I have a 3.8-inch with a 1.25-inch. So wait, sorry, let me take a step back. I have a fender washer that's stainless that has an interior diameter of 3.8-inch, outer diameter of 1.25-inch. And what I'm going to do is there is a little shoe, a tool head, basically, is what they call it with a Dillon XL650. I'm going to basically put that washer on the underside there. The ringer will go up against it, and that should provide decent, even pressure, and I will slowly press on that slinger washer. There is some gap there. I think it's about a credit card width's depth. I'm going to double-check that of gap between the bottom of the lower housing and that slinger. You don't want to press it all the way up against it. There needs to be a gap there. So I'm going to go take a look at a few pictures. I did not measure that when we took it off, which is a mistake. You should probably have measured that gap. I'm going to try to give it my best guesstimate. So yeah, what we're going to do is we're going to go ahead and get this all set up, and then I will give this a try.

[5580 Feather Grass Ln 2.m4a  (47s)]
Okay, I just remembered, I actually have another one of these units that I'm going to go and restore. So what I did is I took the measurement from that unit. It's about a blade's width, like from my utility knife, which turns out to be 0.0255 inches. So it's a pretty narrow gap there. So my approach is going to be very slow, incremental. I'm not going to give it one big push. I'm going to give it really slow and incremental, and then get my blade down there. Once I get my blade down there, that should give me the gap and clearance that I need.

[5580 Feather Grass Ln 3.m4a  (122s)]
Okay, I Got the lower housing completed I did a test fit that's gonna be very important test fit seems, okay It I was able to basically connect the two halves together So the upper part of that armature to the upper bearing just did a quick test fit and I was fine So the next step that I did is I put in the bushing caps There's two of them on the upper housing So basically all I did was I press hand only hand inserted these Into the two side ports, so those are in The next step that we have to do is We're going to have to install the stator And in order for us to do this, we're going to have to do a little bit of wiring and then measuring We want just enough wire coming in to make a good solid connection Without having a lot of excess So it's probably gonna be a little bit of test fitting there making sure that we can get those measurements down In all likelihood Probably what I will do is I will use my regal 9 3 2 8 power supply to basically run Run a test without having hook it up to the main unit this way I can Just make sure that the motor housing is working and the wiring is working And once that's done The upper portion is for the most part at least the motor housing part is going to be done But yeah, that's where we're at right now

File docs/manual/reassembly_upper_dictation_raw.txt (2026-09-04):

[5580 Feather Grass Ln.m4a  (195s)]
The date is true and this is a continuation of our build and reassembly of the LNR Precision Watch Cleaning Machine. So yesterday we completed the installation of the bearing on the lower housing and today we're going to be moving to the installation of the bearing on the upper housing. So a few things that are different between the upper and the lower housing with regards to the bearing. First off the bearing itself it has a on the inside it has a slit that goes top to bottom and on the original during the disassembly you can see where they wrapped wool yarn and then routed that through that slit and then wrapped it on top. So unlike the lower housing bearing where the the wool the wool yarn is riding the outside of the bearing on the upper housing that's going to be riding on the inside in this little slit. Another thing to note is that there is a large washer but the which is uh the same as the lower housing but the the smaller washer sits at the very outer part. On the upper housing that's not really a washer it's more like a felt tab it's it's doesn't have a center cut out. It does have a small little hole in there and I think that's what they used maybe to wrap one line of yarn through there just to kind of connect the piece so that when you oil from the top the the felt pad gets oiled and then that slowly wicks around the capillary action to the bottom of the shaft. So the first thing that I am going to do is I'm going to cut some yarn felt yarn and I'm going to try to mirror the structure that I have here with what was originally on there and see how far that goes. So I probably will poke a little small hole in the top felt and I'll probably have to use my scotch tape in order to thread it through because I don't that won't be too flimsy to get it through and then start wrapping it around and then insert the bearing and then insert the spring the tension spring and then that is technically done from that point. I would just put this little top on the upper housing and that would be done.

[5580 Feather Grass Ln 2.m4a  (107s)]
So, this is just going to record kind of the process I did to get the felt yarn routed through the bearing. So that was actually a little bit complicated, trying to get things tidied up and tightened. What I eventually did is I took the yarn and I tied a knot on both ends about the width of that channel that's inside. That created a knot so that when I routed it, I could loop it through either one end and it would create tension on one side, allowing me to wrap the other side, tie it off, get it tight, and then do the same thing on the other side. So that was kind of the approach I took to get the yarn routed. Now I'm going to go ahead and, oh, before I start there. So I did, on the end that's going to be closest to that smaller felt pad, I did put a little bit of that Scotch tape on there so that I could just route that up through the little small hole that I'm going to create and then cut that off. And then I'll put the larger washer on, of course I'll oil everything up, pre-lube it and then I'll insert the spring and that should be it.

[5580 Feather Grass Ln 3.m4a  (176s)]
This has been a pain. The actual routing of the felt on that upper bearing has been pretty difficult. I actually have failed pretty much every attempt. And basically where you fail is when you insert the bearing, the felt becomes loose and detaches. And so part of that is because the felt is so pliable, it's not really like a thick rope that you can manipulate and create knots in. So what I did now, this is the 15th attempt, I don't know how many attempts it is, is I took the yarn and I took a little round wood and peg, probably about, let me get a measurement, so I had a round peg about 0.4 thousandths of an inch, or 0.400 inches, and I basically started there and I tied a, I don't know if it's a clove hitch or a hitch knot, and then I wrapped it around and I did another knot, so that made it secure. Then I slipped that knot over the bearing end that's closest to the inside of the housing, and I wrapped the other end through the channel, and then I wrapped really tightly around at the very top of the bearing that's closest to the where the oil cap will be or the smaller felt, and I took a little bit of Loctite Super Glue at the very end and I just dabbed a few dabs to lock that in place, because I needed a place to secure one inside. And so far that's working. The problem that I'm completely not sure of is how will that impact the oil wicking process. I don't know, but I could not find a way of securing both ends tightly enough and manipulating it, getting it inside without the whole felt piece falling apart. So, is that the right way? I have absolutely no clue. I guess we'll find out. I have no manual to work off of, so I have no idea. So yeah, we'll find out.

[5580 Feather Grass Ln 4.m4a  (80s)]
Okay, assembly is complete, so I basically, the same approach that I did where I kind of grouted the yarn through, I did use the super glue, I don't know if it's a trick or doing it completely wrong, I guess we'll find out, but it did work, so I was able to insert the bearing, no issue, it seated properly, I put the large washer in, then I put the spring retention in, and then test fitted the armature, and it's working, spins fine, the shaft is lubed, so there's that, and then I went ahead and capped the oil piece, so put this little silver oil cap back on the top of her housing, and obviously the smaller felt washer is just underneath that, so you add oil to the top, it wets that washer, that slowly wicks down to, through the capillary action, through that slotted felt yarn, and it goes down to the bottom and lubricates the washer on the bottom, so upper housing is done, that's complete.

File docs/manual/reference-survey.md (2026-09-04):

# Reference Survey — L&R & Comparable Watch-Cleaning Machine Manuals

> **REPRODUCTION DOCUMENT** — Not an original L&R Mfg. Co. technical publication. This is an internal research note compiled by Hobbs R.E., 2026, surveying publicly available manuals for *comparable* machines to inform an original shop manual for specimen S/N 13505. **No copyrighted text or scanned images from these sources are reproduced in our published manual** — they are used only as references for structure, terminology, and convention. Sources are cited for attribution.

## Purpose
Survey how L&R (and comparable) cleaning-machine documents are organized, so we can adopt the best patterns for an original workshop/shop manual covering the **L&R Master Watch Cleaning Machine, S/N 13505**. Our Master is the earliest in this family (single-jar-rotation, universal series motor, rheostat speed control, 2-wire cord, U.S. Patent 1872812). The machines below are later siblings — same maker, same core operating principle (basket spun through solvent/rinse jars then dried), evolving controls.

---

## Source 1 — L&R Vari-Matic & Vari-Matic III (Operating & Maintenance Manual)
Source: electronicinstrumentservice.com (L&R Mfg. Co., Kearny NJ). **The single most useful template** — closest mechanical relative with the richest maintenance content.

**Machine:** Mechanical (non-ultrasonic) watch cleaner. Universal-type basket motor + separate 1/10 HP indexing/drive motor, "Cal-Rod" 300 W drying heater, **hydraulic column-lift system** (raises/lowers basket), turntable that indexes basket between jars (Geneva wheel), rheostat speed control. Closest descendant of our Master.

**Document structure (its own Index, pp.2):**
- **Operating Instructions:** How to Remove from Crate · Things You Should Know and Do · Important Points to Remember · How to Test Run · Cleaning & Rinsing Solutions and Jars · How to Operate · Recommendations for Best Results
- **Maintenance Instructions:** Bleeding the Hydraulic System · Adjusting Basket Height · Adjusting the Time Cycle · What To Do If Electric Power Fails · The Machine's Switches · Adjusting Basket Motor Speed · Drying of Parts and Spin-Off · Helpful Maintenance Hints · **Machine Diagram and Parts List** · **Wiring Diagram** · **Hydraulic System Diagram**

**Conventions worth stealing:**
- Every page has a black header tab ("Operating Instructions" / "Maintenance Instructions") — clear section banding.
- Each procedure section uses a **bold section title + a labeled line-art illustration in the left margin** with leader callouts (e.g. "BASKET MOTOR", "OUTER COLUMN", "INNER COLUMN", "SCRIBE LINE", "TURNTABLE", "SPEED CONTROL", "FILLER PIPE AND PLUG").
- Maintenance procedures follow a **diagnostic triplet then numbered steps**: *The Trouble* → *The Cause* → *The Remedy*, then "INSTRUCTIONS ON HOW YOU CAN DO THIS" as a numbered list. (Excellent model for our troubleshooting.)
- Numbered step lists for every procedure; cautions inlined in italics/caps ("Do not put solution jars in turntable for this run").
- A consolidated **exploded line drawing** ("Machine Diagram and Parts List") with ~30 leader-labeled parts: Column Top, Lock Nut, Bushing Nut, Column Seal Bushing, "U" Seal, Outer/Inner Column, Column Bushing/Piston/Key/Spring, Hex Nut, Index Arm, Index Locking Disc, Rocker Arm, Geneva Wheel, Basket Motor, Drive Motor, Timer Assembly, Fan Assembly/Blade, Heater Assembly/Bracket, Pilot Light, Push-Button & High-Low switches, Column Bearing, Base.
- **Wiring Diagram page** pairs a schematic (top) with a 3D harness routing drawing (bottom) **plus a wire schedule table** (DET. / REQ. / WIRE color / LENGTH) — e.g. ORANGE 17", GREY 12", GREEN 16", etc. This is a great template for our W-1…W-6 harness BOM.
- **Hydraulic System Diagram** — separate labeled exploded drawing (Cylinder, Cylinder Cap/Gasket/Spring, Outer Seal, Primary/Secondary Cup, Felt Washer, Piston, Filler Pipe, Adjusting Screw, Lock Nut, Union Nuts).
- Strong **safety voice**: explicit caps warning never to use gasoline/benzine/chlorinated solvents (carbon tet, trichlorethylene, perchlorethylene) — health hazard. We should carry a modern solvent-safety note.

---

## Source 2 — L&R Tempo 400 (Operating Manual)
Source: electronicinstrumentservice.com. Later, **solid-state + ultrasonic** machine — shows how L&R modernized the doc.

**Machine:** Fully automatic ultrasonic + mechanical cleaner. Four jar positions, front-panel push-button controls (Power/Start), variable speed via PC boards, ultrasonic generator + transducer, auxiliary dryer, solid-state timer. No hydraulics — mechanical lift.

**Document structure (Index, pp.2):** Introduction · Setting Up · Panel Controls · Preparing for Operation · Operating the Tempo · Work Holding Baskets · Periodic Maintenance · Trouble-Shooting · Electrical Schematic and Diagram · (3× PC-board schematics) · Wiring Diagram (incl. 220 V variant) · Machine and its Mechanical Parts.

**Conventions worth stealing:**
- **Bold sans-serif section headers**, justified body text, a small product photo repeated in the corner of most pages (branding/orientation).
- **Trouble-Shooting as a `Problem:` / `Solution:` pair list** — clean, scannable. (Alternative to Vari-Matic's Trouble/Cause/Remedy; pick one and standardize.)
- **Periodic Maintenance** written as a calendar cadence ("Every six months to a year, apply a light grease…"), naming exact lube points (index column, keyway, gear case, drive train, geneva wheel, bearings) — model for our lubrication schedule.
- Explicit cap'd safety/service boundary: "IMPORTANT — ...DISCONNECT THE MACHINE FROM THE ELECTRICAL OUTLET" before removing the cover; "qualified personnel" caveat. We mirror this for the rewire chapter.
- Setup section gives concrete numbers (overall height ~30", 110-120/220-250 VAC, ~10 A, grounded outlet required) — a "Specifications" habit we should adopt.

---

## Source 3 — L&R Console (Operating & Maintenance Manual)
Source: electronicinstrumentservice.com. **Ultrasonic + mechanical**, stainless column, vinyl-clad cabinet.

**Machine:** Console cabinet; 4-position function switch (Off / Ultrasonic & Dryer / Dryer / Ultrasonic), selector switch (Machine vs Tank), motor rheostat. Ultrasonic tank (6"×6"×6", ~½ gal) + mechanical jars.

**Document structure:** Intro/branding · carton contents checklist · **To Set Up Machine** · **The Machine Controls** (numbered, switch-by-switch) · A Word About the Baskets · L&R Ultrasonic Tank · **Maintenance** (failure-symptom list).

**Conventions worth stealing:**
- **Carton-contents checklist** (bulleted "this carton contains:" with quantities) — good for a restoration "parts inventory / what should be present" page.
- **Controls documented one switch at a time, numbered**, each with what-it-does + a CAUTION where misuse damages the machine. Maps directly onto our plunger / toggle / rheostat.
- A clean **decorative-rule header band** per section (ornamental divider line).
- **Maintenance as a numbered "failure symptom → CORRECTION" list** (e.g. "Motor does not run — CORRECTION: Check motor circuit fuse, motor plug, rheostat, motor brushes for free movement"). Yet another troubleshooting layout to consider; the brush-check item is directly relevant to our universal motor.
- Labeled cabinet illustration with leader callouts (Serial Number, Transducer, Selector/Function switches, Motor Control, Cleaning/Rinsing Solution jars, Drying Chamber).

---

## Source 4 — "Repairing the Hydraulic System of the L&R Vari-Matic" (hobbyist-hosted)
Source: myretrowatches.co.uk. A scan bundling **(a) L&R's official "U" Seal Replacement instruction sheet**, **(b) Vari-Matic synchronizing instructions**, **(c) a Feb-1995 L&R parts price list**, and **(d) a collector's handwritten bench notes**.

**Why it matters most to your goal:** it's the clearest example of a *restorer sharing firsthand knowledge* — exactly what you want to produce. It shows:
- L&R's own **procedure-sheet voice**: a "Caution" preamble ("at best a very difficult matter… recommended you purchase a complete Inner Column Assembly"), then **numbered teardown steps** (Unplug motor → Pull inner column up → Attach wire to spring loop → Remove retaining ring → Withdraw bushing → Remove "U" seal → install/oil/reassemble → **bleed the hydraulic system** → reassemble covers → test).
- **"Helpful Hints"** appended as a bulleted afterword (tricks: how to push the piston out using a 1/4-20 screw in the bottom plug; keep parts scrupulously clean).
- **Synchronizing procedure** as its own numbered sequence (index arm vs secondary shaft alignment).
- **Handwritten marginalia** = the genuine restorer layer: switch wiring states ("RU switch wired normally closed; others normally open"), the **variable resistor identity ("MEMCOR Type 25, 450 Ω, .235 Amp, 7735, ~25–30 watts")** and **final slider resistor "30 Ω 25 watt"**, plus a dated repair log entry. This is the model for our "field notes / what we found" callouts.
- A real **parts list with L&R part numbers + 1995 prices** (e.g. "11035 ACTUATOR W/RETAINING RINGS", "11026 ARMATURE W/RETAINING 117 V", "10164 BLEEDER CUP", "10253 BRIDGE", "10542 GASKET, GEAR CASE COVER (Reservoir)", "10011 HYDRAULIC REPAIR KIT", "10448 MOTOR, END CAP (LOWER)", "30463 MOTOR SOCKET"). Confirms L&R's part-naming style — terse, ALL-CAPS, function-first. Our Part-ID + canonical-name scheme is the modern equivalent.

---

## Source 5 — L&R Master Operating Instructions (our exact machine)
Source: scribd.com/document/456605930 (4-page operating sheet). **Could not extract full page text** (Scribd viewer blocks scraping); only the summary was retrievable: a 4-page sheet covering setup (fill jars, load basket, lower basket, run cycle) across **cleaning → rinsing → drying** stages, with use-and-maintenance guidance.
**TODO:** obtain a clean copy (download from Scribd, or photograph the physical sheet if it came with S/N 13505) so we can transcribe the *original Master* operating sequence verbatim as a primary reference. This is the one document that describes our actual machine.

---

## Cross-Cutting Patterns (the house style to adopt)

1. **Two-part spine:** *Operating Instructions* then *Maintenance/Service Instructions*, each as a banded section. Our manual adds a third part: *Restoration* (firsthand teardown/rebuild) — the part these factory manuals never had.
2. **Front matter:** cover with machine photo + model badge → Index/Contents → carton/parts inventory → specifications (voltage, current, dimensions, motor type).
3. **Illustration-beside-text:** every procedure pairs a numbered step list with a labeled line drawing in the margin; leader callouts use the part's canonical name. (We already have the drawing assets — UH/LH/BRG/ARM/STR/HW + EXP-001/002.)
4. **Procedure format:** bold title → (optional) *Trouble / Cause / Remedy* triad → numbered steps → italic/caps **Cautions** inline → bulleted **Helpful Hints** afterword. Standardize on **Trouble/Cause/Remedy** for service and **Problem/Solution** for the troubleshooting table.
5. **Dedicated diagram pages at the back:** Machine Diagram & Parts List (exploded), Wiring Diagram (schematic + harness routing + **wire schedule table**), and a system diagram for any sub-system (their hydraulics ≈ our bearing/oil-feed + electrical).
6. **Wire schedule table** (color / qty / length / from→to) — we already have this as the W-1…W-6 harness BOM; format it like L&R's.
7. **Strong safety voice in caps** for solvents and for "disconnect before removing cover." We extend it with the modern grounding upgrade and the **green-neck-wire-is-LIVE** hazard.
8. **Terse ALL-CAPS, function-first part names** + part numbers. Our canonical Part-ID system (UH-003, ARM-006, STR-002…) is the disciplined modern version; keep a cross-reference to any known L&R original part numbers where we can find them.
9. **Lubrication on a calendar cadence**, with named lube points and the specific lubricant. We have the materials list (Zoom Spout oil, merino wick, felt washers) — turn it into a schedule.

## Originality / licensing reminder
Write all manual prose original. Use these only for structure and terminology. Cite each source in a "References" appendix. Reproduce **none** of their scanned figures — our figures are our own SVG drawings and our own restoration photos. (Repo license still TBD; this note doesn't change that.)

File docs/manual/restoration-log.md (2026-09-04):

# Restoration Log — L&R Master Watch Cleaning Machine, S/N 13505

> **REPRODUCTION DOCUMENT** — Not an original L&R Mfg. Co. technical publication. Reverse-engineered from hands-on restoration of specimen S/N 13505. Curated by Hobbs R.E., 2026. For restoration reference only.

**What this is:** the as-performed *restoration/refinishing* procedures (the companion to `teardown-log.md`, which is disassembly). This is the source material for **Part III (Restoration)** of the shop manual — each entry becomes a formatted procedure. Capture the as-found condition, the materials/products, the technique, and the result.

**Per-entry schema:** Part ID(s) · as-found condition · materials/products · tools · technique/step sequence · result · cautions · photo ref · provenance.
**Provenance tags:** (CONFIRMED) done & verified · (RECALL) reconstructed from memory · (VERIFY) needs a check before publishing.

---

## R-1 — Gasket / jar seal reconditioning
- **Part ID:** **PLT-002** (tapered jar seal gasket) — the single molded rubber piece carrying the molded mark **U.S. PATENT 1,872,812**. Tapered to wedge into the glass jar mouth and seal the jar around the spinning basket so cleaning solution doesn't splash out. *(Confirmed = the conditioned gasket, not a separate cap seal.)* **Note:** patent 1,872,812 is L&R's 1930/1932 "Watch Cleaning Machine" patent (inventor Frank Regero) covering the basket-mounting mechanism — molded here as a **maker's mark, not a seal patent** (CONFIRMED via Google Patents 2026-06-20; see CLAUDE.md External Reference Intel).
- **As-found condition:** rubber was **dried out and almost degraded** — stiff, brittle, losing pliability; risked cracking/failure if used as-is. Surface carried an orange-brown chemical film.
- **Materials/products:** **SEKODAY Treadmill Belt Lubricant** — components: **silicone oil (non-cracking type), 100%** (Jiashan Sekoday Trading Co.; bought on Amazon). Sold as a treadmill-belt lubricant but it is pure silicone oil — appropriate for the rubber gasket. Warm Citranox solution for the pre-clean. *(Product name CONFIRMED by box photo 2026-06-20.)*
- **Tools:** soak vessel; microfiber cloth.
- **Technique / step sequence:**
  1. Cleaned with warm Citranox solution to remove the orange-brown chemical film (patent text came back crisp).
  2. **Immersion soak** in the SEKODAY silicone (16+ hours) to fully re-saturate the rubber.
  3. Microfiber-buffed to a full satin-black finish.
- **Result:** rubber **fully re-saturated and pliability restored** — structurally sound again, patent text crisp.
- **Caution:** **WD-40 ruled out** for rubber contact — petroleum distillates swell and degrade vintage elastomers. Use silicone only. (The SEKODAY box confirms it: silicone has "a good effect on plastic/rubber products and cannot replace metal lubricants" — so silicone for the gasket, oil for the bearings.)
- **Photo:** see `photos/gasket/`.
- **Provenance:** (CONFIRMED) — done and verified (pliability restored); product name CONFIRMED 2026-06-20 (SEKODAY Treadmill Belt Lubricant = silicone oil, non-cracking type).

---

## R-2 — Cosmetic refinishing of the motor housings (strip → prep → wrinkle topcoat → cure)
- **Part IDs:** **UH-001** (upper housing) + **LH-001** (lower housing), both halves; mating flanges **FLG-001**; cooling vents **UH-007**; internal bores/chambers masked off.
- **As-found condition:** decades of factory **baked-on enamel, oil varnish, and grease** — a cross-linked finish bonded into the porous aluminum castings.
- **Materials/products:** **Citristrip** (citrus-based paint & varnish stripper gel — safe on aluminum); **99.9% IPA** for the final pre-paint wipe; **Rust-Oleum 249322 Self-Etching Primer** (zinc-phosphate base); **VHT SP201 Wrinkle Plus** high-temp topcoat (black); **high-temperature automotive masking tape**.
- **Tools:** submersion/soak vessel; wire brushes + detailing picks; abrasive pad / wire wheel; razor blade (mask trimming); spray cans; heat gun (and/or oven).
- **Technique / step sequence:**
  - **Phase 1 — Chemical strip & degrease:** coated the castings with **Citristrip stripper gel** and let it dwell to lift the cross-linked factory finish (citrus-based, **safe on the aluminum substrate**); used **wire brushes + detailing picks** to work the softened finish out of the deep cooling fins, internal chambers, and anti-rotation notches; **removed all stripper residue (scrape / wipe / rinse) and dried immediately** to prevent flash-rust / white oxidation on the raw aluminum.
  - **Phase 2 — Surface prep & masking:** lightly **scuffed the exterior raw aluminum** with an abrasive pad / wire wheel to give the primer "tooth"; **precision-masked the running faces** with razor-trimmed high-temp tape — the **0.800" total-height internal chamber**, the **0.600" upper bore** + **0.500" bottom exit bottleneck shelf**, the **0.400" inner clearance channel walls**, and **all mating flanges (FLG-001)** where the end-bells bolt together.
  - **Phase 2.5 — Final IPA wipe + self-etching primer:** **immediately before priming, wiped everything down with 99.9% IPA** (skin oils / stray turbine oil / chemical film), then applied **Rust-Oleum 249322** in ultra-thin continuous coats; matte olive-drab/grey appearance confirmed a proper anchor.
  - **Phase 3 — VHT Wrinkle Plus topcoat (heavy 3-coat crosshatch):** wrinkle finish needs a thick, heavy film to crowd the molecules so they ripple — laid down 3 heavy crisscrossing coats: **Coat 1 horizontal → Coat 2 vertical (5-min flash) → Coat 3 diagonal (5-min flash)** for uniform multidirectional thickness over the rounded contours; kept **flash windows tight** so the layer stayed one singular bound wet film (no premature skinning).
  - **Phase 4 — Thermal cure / wrinkle activation:** applied **controlled heat (heat gun and/or oven, ~350°F after the level window)** to draw out a uniform texture across the varying metal thickness; the thick wet coat shifted from gloss liquid to a tight, uniform industrial matte wrinkle. **Masking pulled while the film was still warm** to preserve internal mechanical dimensions.
- **Result:** tight, uniform heavy wrinkle grain on both housing halves, matching the vintage L&R Master aesthetic; mechanical tolerances preserved. Cure complete — ready for reassembly.
- **Cautions:** ⚠️ remove all Citristrip residue and **dry immediately** (raw aluminum flash-rusts fast); ⚠️ wrinkle texture only develops with a **heavy film + tight flash times** and **uniform heat**; ⚠️ mask every running face/bore/flange; ⚠️ pull masking **while warm**.
- **Photo:** see `photos/housing/`.
- **Provenance:** (CONFIRMED) done & verified. NOTE: the finish was stripped with **Citristrip** (paint/varnish stripper gel) — earlier drafts wrongly named "Citranox"; **Citranox was used only on some mesh basket pieces** (see R-3), not the housings. Coat order is **horizontal → vertical → diagonal** (an earlier summary listed vertical/horizontal/uniform). CLAUDE.md reconciled to match.

---

## R-3 — General ultrasonic cleaning / degrease of small parts (during disassembly)
- **Part IDs:** essentially **all small disassembled hardware that fit the tank** — bearings (BRG-001/002), fasteners (FLG-002, STR-008, UH-004/005, SPN-005/007, PLT-005), shaft collars (ARM-008/009), washers, oil feed tube (LH-006), small brackets, etc. **Oversized parts that did not fit the tank** (housings, base/body casting, neck/pillar) were **cleaned by hand**.
- **As-found condition:** service grime — old turbine/cleaning-fluid oil, grease, and light surface oxidation on the disassembled parts.
- **Materials/products:** **mild soap (dish/parts detergent), diluted**, in warm water, run in the **ultrasonic tank**. Mild/neutral chosen deliberately — safe across the mixed materials (steel, brass, aluminum, phenolic). (Finish stripping used Citristrip — R-2; Citranox was reserved for some mesh basket pieces.)
- **Tools:** ultrasonic cleaning tank; hand brushes / cloths for oversized parts.
- **Technique / step sequence:** as each sub-assembly came apart during teardown, small parts were dropped into the ultrasonic tank with the **diluted mild-soap solution** to degrease and clean, then rinsed and dried. Anything too large for the tank was cleaned by hand.
- **Result:** all hardware degreased and clean — ready for inspection, measurement, and reassembly.
- **Cautions:** ⚠️ **ultrasonic degreasing strips all lubrication** — re-oil the bearings (BRG-001/002) and wear surfaces before/at reassembly (see R-7/R-8); ⚠️ **dry parts promptly** (raw steel/aluminum flash-rusts); ⚠️ keep the chemistry mild — aggressive cleaners can attack aluminum/phenolic.
- **Related (heavier clean):** **some of the mesh basket pieces (BSK-002)** carried baked-on chemical-fluid sludge and got a dedicated **Citranox** clean to cut it — a stronger detergent than the general mild-soap bath (CONFIRMED 2026-06-20).
- **Photo:** see `photos/` (per-assembly subfolders: `bearings/`, `hardware/`, `basket/`).
- **Provenance:** (CONFIRMED) general mild-soap ultrasonic clean during teardown; some mesh basket pieces cleaned with Citranox (CONFIRMED).

---

## R-4 — Bearing system rebuild: materials selection & sourcing
*Companion to the install procedures **R-7** (lower housing) and **R-8** (upper housing) — this entry covers the overhaul strategy, what was worn vs sound, and the material choices/sourcing. The step-by-step installs live in R-7/R-8.*
- **Part IDs:** spherical sleeve bearings **BRG-001** (upper) / **BRG-002** (lower); reservoir yarn **BRG-008**; felt washers **BRG-009** (large) / **BRG-010** (small); lower retaining ring **BRG-011**; conical tension springs **BRG-012**; oil wick (GE); oil.
- **As-found condition:** the **bearings themselves were sound** (self-aligning spherical sleeve type — cleanable and reusable). The **consumables were spent:** original felt washers were **brittle and broke apart** on disassembly; the reservoir was a **natural wool-felt yarn/string** threaded through the bearing's central lube hole/slit and wrapped around the globe — dried out, oil long gone. *(as-found = RECALL from teardown + R-7 dictation.)*
- **Reused (original, not replaced):**
  - **BRG-001 / BRG-002 bearings** — cleaned (general mild-soap ultrasonic, R-3) and reused; geometry confirmed good (see bearings dimension sheet).
  - **BRG-012 conical springs** — **original factory springs reused** (CONFIRMED). The **Century Spring TA-2226CS** was identified as the dimensional equivalent / source-if-needed (302/304 SS, large OD 0.750", small OD 0.500", free length 0.440", wire 0.0625") but was **not installed**.
- **Replaced consumables (new stock + rationale):**
  - **Reservoir yarn (BRG-008):** **Estako Wool 98 — 100% Superwash Merino Worsted, off-white/un-dyed.** Chosen un-dyed so it **won't leach dye or mat** when oil-saturated; merino gives good capillary draw to feed oil to the shaft.
  - **Felt washers (BRG-009 / BRG-010):** **SAE F3 hard wool felt** — replaces the disintegrated originals; hard felt holds shape as a dust block + oil-containment washer at the pocket edges.
  - **Oil wick:** **GE 1/8" vintage-fan oil wick** (~1¼" cut), tied to the yarn to carry oil through the port / bearing slit.
  - **Oil:** **Bramec Zoom Spout** multi-purpose turbine oil.
- **Original factory lube design (reference, drives the material choices):** a continuous natural yarn threaded through the central lube hole to contact the shaft, the remainder wrapped around the bearing globe; flat wool-felt washers at the pocket edges for dust blocking and oil containment. The modern stock above mirrors that scheme.
- **Result:** a complete, matched consumable set ready to install — executed in **R-7** (lower) and **R-8** (upper).
- **Cautions:** ⚠️ ultrasonically cleaned bearings are **bone-dry — must be re-oiled** before/at install; ⚠️ use **un-dyed** yarn (dye can leach into cleaning solvents); ⚠️ keep felt + yarn **oil-saturated** for the capillary feed to work.
- **Photo:** see `photos/bearings/`.
- **Provenance:** (CONFIRMED) materials + reuse decisions (springs + bearings reused); as-found condition (RECALL) from teardown/R-7 dictation.

---

## R-6 — Platform gasket re-fastening (rivet → serviceable screw set)
- **Part IDs:** PLT-005 (gasket deck fastener), PLT-001 (platform disk), PLT-002 (tapered jar seal gasket).
- **As-found:** the tapered rubber gasket (PLT-002) was **riveted** to the metal platform disk (PLT-001) by **4 permanent rivets** through 4 of the 6 holes on the 2.300" circle. The rivets had to be **drilled out** to remove and service the gasket — they are not reusable.
- **Restoration decision (terminal fix):** replace the 4 rivets with a **serviceable screw-and-nut set** so the gasket can be removed for future service — consistent with the main motor-cap gasket hardware upgrade (screw-and-nut for even compression / serviceability).
- **Hardware:** per hole (×4) — **stainless M4-0.7 × 10 mm flat-head Phillips screw + stainless M4-0.7 hex nut**, reusing the **original flat washers (PLT-006, OD 0.4385")**. Only the rivet shank was replaced; the washers are original and retained.
- **Technique / notes:** the **flat (countersunk) Phillips head** gives the flush finish — no trimming needed (resolved the earlier length question). New screw + nut are **stainless steel**. Original rivet dimensions are unrecoverable (destroyed on removal).
- **Result:** gasket now serviceable/removable; deck fastening restored.
- **Provenance:** (CONFIRMED) decision + hardware; final screw length (VERIFY after trimming).
- **Note for drawings:** the engineering sheets are reverse-engineered ORIGINAL design — show the **original rivet** as the design of record, with a note that the restoration substituted the M4 screw/nut/washer (this entry is the citation).

## R-7 — Lower-housing bearing reinstallation (Reassembly Phase 1)
*Source: voice dictation 2026-06-19 (5 memos). Raw: `reassembly_bearings_dictation_raw.txt`. Note: no public instructions exist for this — method is the restorer's reconstruction from the as-found wick/felt arrangement.*
- **Part IDs / materials:** lower housing **LH-001**; lower bearing **BRG-002** (notched at the bottom — installs one way only, must seat in the notch); conical tension spring **BRG-012**; large + small **SAE F3 felt washers** (**BRG-009** large / **BRG-010** small); bottom **metal retaining ring BRG-011**; oil-wick reservoir = **wool yarn (BRG-008)** tied to a **GE 1/8" oil wick** (the type for 1920s–30s fans), cut ≈ 1¼"; oil = **Bramec Zoom Spout** multi-purpose turbine oil.
- **Procedure (as performed):**
  1. Cut ≈ 1 ft of wool yarn and ≈ 1¼" of the 1/8" oil wick; **tie the yarn to the wick** with tight knots.
  2. **Route the yarn through the oil-wick port.** The yarn is floppy — stiffen the lead end with a small wrap of **Scotch tape**, then pull it through with **tweezers**.
  3. **Small felt washer (BRG-010)** sits **flush at the bottom of the bearing** (it contacts the incoming wick → that's how the lower felt gets oiled). Route the yarn **up the side** of the bearing; wrap it in concentric turns around the **top neck**, capturing the **large felt washer (BRG-009)** on top (oil wicks up the yarn to the upper felt — capillary feed).
  4. Seat the **bearing (BRG-002)** into the housing — mind the **bottom notch** (one orientation only).
  5. **Pre-lubricate** the felts + yarn with Zoom Spout oil; let it sit on plastic to soak (capillary).
  6. Insert the **tension spring (BRG-012)** into the housing.
  7. Install the **retaining ring (BRG-011)** at the very bottom over the felt — **friction fit**; tap it down with a **brass flat punch (Grace USA)** + light **rubber-mallet** taps, working **evenly around the ring** until flush.
  8. **Clean the bearing bore** with alcohol prep pads (clear install debris).
  9. **Test-fit the armature** — fit confirmed good.
- **Cautions:** ⚠️ **No steel tools under pressure** — steel mars the bearing/housing. Use **brass punches** (soft, won't mar) and light, even force only.
- **New/confirmed dimension — BRG-011 retaining ring:** OD **0.500"**, ID **0.295"**, thickness **1/16" (0.0625")** (CONFIRMED). (This is the existing BRG-011, now measured + characterized as a friction-fit ring; flag for a drawing callout.)
- **Note (bearing generations):** this wick/felt capillary oiling is the **early OILED sleeve-bearing** design (our machine). Later Masters used **sealed** bearings (manual: "never requires oiling"); a roller-bearing variant is hobbyist-claimed but unconfirmed. (The "Mark 1/Mark 2" labels are collector shorthand, not L&R nomenclature — see CLAUDE.md External Reference Intel.) Effectiveness of the capillary feed vs. a sealed setup is unknown, but it's the original design intent for this generation.
- **Figures** (`photos/bearings/`):
  - `R7-01-kit-layout.jpg` — components laid out: bearing sleeve, conical spring (BRG-012), large + small SAE F3 felt washers, jar gasket, lower housing *(pre-assembly)*
  - `R7-02-old-vs-new-wick.jpg` — degraded original felt/wick vs fresh wool yarn + GE felt wick *(as-found vs replacement)*
  - `R7-03-yarn-measured.jpg` — wool yarn cut to length on the rule *(Step 1)*
  - `R7-04-tape-stiffened-lead.jpg` — Scotch-tape-stiffened lead end; yarn routed through the port *(Step 2)*
  - `R7-05-yarn-through-port.jpg` — macro of wool yarn descending through the oil-wick port into the bore *(Steps 2–3)*
  - `R7-06-felt-ge-wick-port.jpg` — felt + GE oil wick protruding at the port neck *(Step 3, capillary contact)*
  - `R7-07-bore-spring-seated.jpg` — down-the-bore: BRG-002 seated with the BRG-012 spring coils around it *(Steps 4 + 6)*
  - `R7-08-armature-testfit.jpg` — armature shaft test-fit through the bearing *(Step 9, fit confirmed)*
  - **R-7 photo set COMPLETE (8 figures).** No in-situ Step-7 BRG-011 retainer-ring shot — the ring is now seated/buried at the housing bottom and can't be re-shot without teardown. It is fully bench-dimensioned (OD 0.500" / ID 0.295" / 1/16") and the loose ring appears in the bearing dimension photo set (`photos/bearings/`), so the gap is closed by reference rather than a new photo.
- **Provenance:** (CONFIRMED) as-performed 2026-06-19; lower housing bearing installed + armature test-fit good. *Upper-housing bearing install is next → R-8.*

## R-8 — Upper-housing bearing reinstallation (Reassembly Phase 1, cont.)
*Source: voice dictation 2026-06-20 (4 memos). Raw: `reassembly_upper_dictation_raw.txt`. No public instructions exist — method is the restorer's reconstruction from the as-found wick/felt arrangement. This was the harder of the two installs (15+ failed attempts before a working method).*
- **Part IDs / materials:** upper housing **UH-001**; upper bearing **BRG-001** (has an internal top-to-bottom **slit/channel** in the bore); conical tension spring **BRG-012**; **large felt washer BRG-009** (center cutout, same as lower); **upper small felt = a solid felt TAB/PAD** (NOT a cutout washer — sits at the very top/outer, under the oil cap; has only a tiny pin-hole); reservoir = **wool felt yarn (BRG-008)**; oil access cap **UH-011** ("OIL"-stamped silver dome); oil = **Bramec Zoom Spout**. **No BRG-011 retaining ring** (upper housing does not use one).
- **Key differences vs R-7 (lower housing):**
  1. **Yarn rides INSIDE the bearing** — routed through the bearing's internal slit/channel (the original showed yarn wrapped through this slit and over the top), versus the lower housing where the yarn rides the OUTSIDE of the ball.
  2. **Top felt is a tab/pad, not a washer** — no center cutout, just a pin-hole; it sits at the very top under the **oil cap (UH-011)**. Oiling sequence: oil added at the top → wets the felt pad → capillary-wicks down the slotted yarn → lubricates the bottom washer + shaft.
  3. **No bottom retaining ring** (no BRG-011) — bearing + large washer + spring only.
- **Procedure (as performed — the working method, after many failures):**
  1. Cut wool felt yarn; goal is to mirror the original slit-routing.
  2. **Failed approaches (recorded for the manual):** knotting both ends to the channel width let the felt detach/loosen the moment the bearing was seated — the yarn is too pliable (not a stiff rope) to hold knots under handling.
  3. **Working method (~15th attempt):** tie the yarn around a small **round wood peg (~0.400" dia)** with a clove-hitch/hitch knot, add a second knot to secure → slip that knot over the **bearing end nearest the housing interior**; route the other end **through the bearing's internal channel**; wrap it **tightly around the top** of the bearing (the end nearest the oil cap / small felt); **dab a little Loctite Super Glue** on the terminal end to lock it (needed one anchored end).
  4. On the lead end closest to the small felt pad, stiffen with a touch of **Scotch tape** and thread it up through a small poked hole in the felt; trim.
  5. **Seat the bearing (BRG-001)** — once glued it seated properly with no detachment.
  6. Fit the **large felt washer (BRG-009)** on top.
  7. **Pre-lubricate** everything with Zoom Spout oil.
  8. Insert the **tension spring (BRG-012)**.
  9. **Test-fit the armature** — seats and **spins fine**, shaft lubed.
  10. **Cap the oil port** — silver **OIL cap (UH-011)** back on the top of the housing; the small felt pad sits just underneath it.
- **Cautions / open question:** ⚠️ same no-steel-under-pressure rule as R-7. ⚠️ **Effect of the super-glue anchor on long-term oil wicking is unknown** (restorer's note) — flag **(VERIFY)**: watch oil flow/feed over time; the glue was a last resort to keep the pliable felt from detaching during seating, with no manual to reference.
- **Figures** (`photos/bearings/`):
  - `R8-01-kit-layout.jpg` — upper housing + old vs new felt pads, springs, wick, bearing laid out
  - `R8-02-top-felt-tab.jpg` — the top felt pad/tab seated in the collar (under the oil cap)
  - `R8-03-bore-yarn-slit.jpg` — bearing bore showing the yarn routed through the internal slit + spring
  - `R8-04-bore-bearing-spring.jpg` — bore detail, bearing + BRG-012 spring seated
  - `R8-05-interior-seated.jpg` — upper-housing interior (vented spider), bearing seated
  - `R8-06-interior-seated-detail.jpg` — interior close-up, bearing + spring seated
  - `R8-07-oil-cap-exterior.jpg` — UH-011 "OIL" cap installed on the dome
  - `R8-08-oil-cap-exterior-alt.jpg` — exterior dome / oil cap, alt angle
- **Provenance:** (CONFIRMED) as-performed 2026-06-20; **upper-housing bearing installed + armature test-fit good. Phase 1 (bearings & lubrication) COMPLETE — both housings done.** Super-glue wicking effect = (VERIFY) over time.

## R-9 — Armature into lower housing + ARM-010 slinger seated (Reassembly Phase 2 — start)
*As-performed 2026-06-21 (Father's Day). Source: voice dictation, 3 memos → `reassembly_r9_dictation_raw.txt`. First mechanical-assembly step: marries the armature to the lower housing and presses the external slinger onto the lower journal.*
- **Part IDs:** armature **ARM-001** (lower journal **SHF-003**); lower housing **LH-001** (with **BRG-002** + felt/spring already installed, R-7); **4 phenolic end-float washers** — **ARM-012** (small) + **ARM-011 ×3** (large); **ARM-010** brass slinger.
- **Procedure (as performed):**
  1. **Stack the 4 phenolic washers on the fan/lower-journal end of the armature** — **ARM-012 (small) against the bearing seat, then ARM-011 ×3** above it.
  2. **Set the lower housing (LH-001) onto the armature** so the lower journal (SHF-003) passes down through the lower bearing (BRG-002).
  3. **Invert the assembly and place it in a press.**
  4. **Press the slinger (ARM-010) onto the protruding journal end with slow, INCREMENTAL axial pressure** — ⚠️ **do NOT bottom it out against the housing; leave a small running gap.** Target gap (lower-housing face → slinger) ≈ **0.0255"** (a utility-knife-blade width). Press in small steps and **gauge the gap with a knife blade / feeler** until it just slips in. *(The gap on the as-found machine was not measured before removal — a noted mistake; the 0.0255" value was taken from the restorer's SECOND L&R unit as the reference.)*
- **Tool used (restorer's improvisation):** a **Dillon XL650 progressive reloading press, used as an arbor press** — the press platform/toolhead served as the anvil; a **stainless fender washer (Everbilt, 3/8" ID × 1‑1/4" OD)** was used as the **driver** bearing on the slinger face. The **3/8" (0.375") bore clears the ~0.28" journal**, and the **1‑1/4" OD covers the slinger's ~0.81" face**, so pressure is applied to the slinger, never the shaft tip. *(The fender washer is a TOOL, not a machine part — not in the BOM.)*
- **Accessible-equivalent methods (for the manual — most won't have a reloading press):** the canonical tool is a **1‑ton bench arbor press**; alternatives are a **bench vise closed slowly as a press**, or a **drill-press quill pressed down without rotating.** In every case use a **tubular driver / deep socket / fender washer** whose **bore clears the shaft** and whose **flat face bears on the slinger** — apply slow, even pressure; **never hammer.** The Dillon-press method maps directly to "arbor press + fender-washer driver."
- **Result:** ARM-010 slinger seated to the **~0.0255" gap** (not bottomed); armature mounted in the lower housing — **lower housing COMPLETE.**
- **Follow-on (same session — all TEST-FIT, nothing finalized yet):**
  1. **Upper-housing test-fit:** the armature's upper journal (SHF-002) seats into the upper bearing (BRG-001) — good.
  2. **Brush-port caps/plugs (UH-004):** the two brush-port pieces pushed into the upper-housing brush ports (UH-003) — **finger force, or gentle light taps with a rubber mallet**; both seated. *(Restorer's term: "brush ports"; canonical = UH-004 cap into UH-003 port.)*
  3. **Stator (STR-001) test-fit:** stator set into the upper housing; its **lead clip attaches to one of the brush ports** (field-coil lead → brush connection point — note this for the electrical phase).
  4. **Full motor test-fit:** lower + upper housings joined again — **everything fits and the armature spins FREELY ✓** (resolves the rotor-spins-free check).
  *(Still test-fit only — halves not torqued, stator not finally wired. Next = R-10: stator field-coil wiring (measure/cut to length) + standalone bench test on a Rigol DP932A DC supply (low-voltage DC smoke-test, NOT mains) + final join/torque.)*
- **Cautions:** ⚠️ even **axial** pressure only; driver must clear the shaft tip/threads and bear on the slinger face; ⚠️ no steel hammer on the cast aluminum; ⚠️ the 4 phenolic washers set the fan-clearance height — don't over-press.
- **Figures** (`photos/bearings/`):
  - `R9-01-press-setup.jpg` — Dillon XL650 set up as an arbor press, housing inverted under the toolhead
  - `R9-02-fender-washer-driver.jpg` — the Everbilt 3/8" ID × 1‑1/4" OD stainless fender washer (the driver)
  - `R9-03-in-press.jpg` — armature/lower-housing assembly under the press, journal up
  - `R9-04-shellplate-detail.jpg` — top-down of the shellplate with the journal + slinger centered
  - `R9-05-slinger-seating.jpg` — slinger pressed against the anvil block (the seating moment)
  - `R9-06-result-side.jpg` — finished lower-housing power head, side view (slinger seated, rotor/commutator exposed)
  - `R9-07-result-slinger-detail.jpg` — top-down of the seated slinger at the housing neck
  - `R9-08-press-process.mov` — silent process clip of the press action
- **Provenance:** (CONFIRMED) as-performed 2026-06-21. **Phase 2 (mechanical) STARTED.**

## R-10 — Motor electrical bench test (Rigol DP932A) + verified wire map
*As-performed 2026-06-21. Source: voice dictation (5 memos) → `reassembly_r10_dictation_raw.txt`. Standalone low-voltage DC smoke-test of the motor on a Rigol DP932A (CH1), NOT mains. Resolves ledger E2 (wire map) + E3 (bench test).*
- **✅ RESULT: motor runs and SELF-STARTS on low-voltage DC** (no hand-start needed) → windings, brushes, and commutator all good; rotor spins freely under power.
- **VERIFIED MOTOR WIRE MAP (bench-confirmed):**
  - **GREEN + BLACK = the run pair** — the field + armature in series. Connection that spun it: **Green → CH1 (+), Black → CH1 (−)**, **White left floating.**
  - **WHITE = the third lead / center tap** (the rheostat/reverse branch; open for the bench test). ⚠️ **Refined 2026-06-23 — see R-10 cont. below: WHITE is NOT a dead tap. It is the second direction-return lead; green stays common and the return selects black vs white to reverse spin.**
  - Polarity: green(+)/black(−) gave rotation; swapping +/− reverses direction (universal motor). *(The machine's actual reversing function does not swap the supply polarity — it swaps the return lead between black and white; see R-10 cont.)*
- **V/I at run (Green +, Black −, White floating):** **begins to turn at ~12 V, ~0.5 A** (current-limited at 0.5 A); spins faster with more voltage / current headroom. Spins slowly overall since 12–30 V ≪ its 110 V rating. (Consistent with a ~60 W / 110 V motor overcoming stiction at low DC.)
- **Diagnostic journey (valuable for the manual):** first attempts powered **Black–White**, which energized **only the field** (steady ~0.5 A, no torque) because that pair leaves **green's brush out → the armature loop is open.** The breakthrough: **GREEN is one END of the field+armature series (a brush lead)** and must be powered; WHITE is the tap. ⚠️ **Do not bridge two leads together** (e.g., black+white to one terminal) — that can short the field and kill torque. Always power **two leads, third floating.** Commutator was cleaned + brushes seated beforehand.
- **Neck-cable wiring prep (planned/in-progress, from dictation):** new SJOOW 16/3 — outer sheath pulled back **~5.5"** from the 3-wire plug for working room. **GREEN** (hot, RED heat-shrink) is the longest: trim to **~4.5"**, with a **brass clip soldered on** that attaches to a brush port. **BLACK + WHITE** (black/white heat-shrink) trimmed to **~3.25" each**, spliced/soldered to the existing motor leads. Each joint gets heat-shrink; then a larger black heat-shrink + the **nylon braided loom** covers the whole bundle down to the control unit. ✱ Soldering done with the **stator (STR-001) removed** for clearance — route the 16-ga through the upper-housing port, solder to the stator outside, feed it back in. Method: tacky flux + **lead-free solder**, tin a pad then set the wire.
- **⚠️ Sequence note (why the dictation is "out of order"):** the bench test above was run with **TEMPORARY electrical-tape connections** — the restorer chose to **verify the motor runs BEFORE committing to solder** (smart). The **final soldered wiring** (green brass clip + black/white splices, heat-shrink, nylon loom) is **still to be completed → R-11 (final motor wiring).**
- **For the verified schematic / full ring-out:** black+green = the motor series; white = the tap. Reconcile with factory diagram **E-1690** (green = the rheostat-side motor lead — consistent: the rheostat sits in series at the green end). Green's "LIVE" red-flag still stands.
- **Figures:** `photos/stator-wiring/R10-01` (full bench: motor on stand + Fluke meter + Rigol DP932A), `R10-02` (Rigol display at the 0.500 A current limit), `R10-video.MOV` (motor run on DC). Filed 2026-06-23 from IMG_1937/1938/1939.
- **Provenance:** (CONFIRMED) bench test 2026-06-21.

### R-10 (cont.) — Reversing behavior confirmed on the bench (2026-06-23)
*As-performed 2026-06-23. Same standalone setup: Rigol DP932A (CH1) low-voltage DC, NOT mains, temporary connections. Resolves the question of WHITE's role and bench-confirms the machine is a reversible model.*
- **✅ FINDING — direction is selected by the RETURN lead, not by supply polarity.** Holding **RED (+) on GREEN** and moving the **(−) lead between BLACK and WHITE** reverses the direction of rotation:
  - **GREEN (+) → BLACK (−):** spins one way (e.g. CW).
  - **GREEN (+) → WHITE (−):** spins the other way (e.g. CCW).
  - (CW/CCW assignment as viewed from a fixed end — record the reference end when the final orientation is fixed; not critical to the wiring logic.)
- **Corrected understanding of the wire map:** **GREEN = the common live lead** (the brush/armature-series end that is always energized). **BLACK and WHITE = the two reversing leads** — the two ends of the field path. Energizing green→black sends current through the field one way; green→white sends it the other way, flipping field polarity relative to the armature → the rotor reverses. This is the classic series/universal-motor reverse-by-swapping-the-field scheme. WHITE is therefore **not** a dead "tap" — it is the second-direction lead. (The earlier R-10 note "WHITE = floating tap" reflected only that white was left open while proving the motor runs in one direction.)
- **Reconciles the earlier "no torque on black–white" result:** black↔white with green open still gives no torque — that path is field-only and leaves the armature/green brush out of circuit. The reversing function keeps **green in circuit at all times** and only switches which of black/white completes the return. Always two leads live, never bridge black+white together.
- **⚠️ Mechanism = best-judgment (no original L&R service manual exists):** most likely the field is brought out as two leads (or a tapped/two-section field) with green as the common armature-side brush lead; the original machine's **red plunger switch** does this black↔white swap as a momentary motor-REVERSE control. Bench behavior is CONFIRMED; the exact internal field topology is (SYN)/inferred until ring-out of the assembled control wiring.
- **Significance:** this is the bench corroboration that **S/N 13505 is a reversible-motor model** — consistent with (a) the 3-wire BLK/WHT/GRN neck loom (forums note the 3-wire loom appears only on reversible units), (b) factory diagram E-1690's green = motor↔rheostat branch, and (c) the operating-manual instruction to *reverse the basket in each jar*. It advances ledger **E5** (plunger = reverse): the reverse FUNCTION is now bench-proven; only the mapping of black/white to the physical plunger/toggle remains for the assembled ring-out.
- **Provenance:** (CONFIRMED) bench test 2026-06-23. Final wiring → R-11 below.

## R-11 — Final motor wiring + Phase 2 mechanical close-out (2026-06-23)
*As-performed 2026-06-23. Commits the bench-verified wire map (R-10) to the final connection and completes the power-head assembly. Resolves ledger E1/E7 (wiring) and M1/M2 (mechanical).*
- **FINAL MOTOR CONNECTION (confirmed):**
  - **GREEN → brass clip mounted on a brush** — the common live / armature-series lead (RED heat-shrink on green = LIVE, not ground; ledger E6).
  - **BLACK → black field lead from the stator (STR-001).**
  - **WHITE → white field lead from the stator (STR-001).**
  - This matches the R-10 reversing map exactly: green is the common brush lead; black & white are the two stator field-path leads that select direction.
- **Mechanical close-out (Phase 2 complete):** **ARM-013 ×4 phenolic end-float washers installed** on the upper journal (against BRG-001) at the join (M1); **housings joined and FLG-002 tie-bolts torqued** into the UH-009 bosses (also clamping the deck via PLT-004); **platform deck (PLT-001/PLT-002) → spindle SPN-002 (SPN-005 set screw) → basket BSK-002 + lid → mounted to the body** (M2).
- **State:** the **motor / power head is now closed** — mechanically assembled and electrically wired. Open items left on the package are documentation-only (drawing rework to add ARM-013; title-block rename). The remaining electrical work (rheostat/dropping-resistor metering, plunger/toggle role confirmation, full verified schematic, 3-wire grounded rewire → R-5) is **control-unit / main-unit** scope.
- **Figures:** `photos/stator-wiring/R11-01 … R11-17` (17 shots): green wire + soldered brass brush-clip fabrication; clip attached at the brush port; black/white field-lead routing into the housing; halves-open wiring; assembled motor; new SJOOW cable prep; rewired stator; lead-prep (green→RED heat-shrink, R11-14); assembled-motor cable routing (R11-15); stator clips with mixed red + yellow/green marking (R11-16); assembled front with yellow/green-to-brush (R11-17). (Filed 2026-06-23 from IMG_1282–1291, 1581, 1686, 1693, 1908, 1929, 1931, 1932.)
- **Heat-shrink color (RESOLVED 2026-06-23, per restorer):** the **green LINE lead is marked RED** (R11-14) — correct "live, not ground." The **yellow/green** band (R11-16/17) marks an **INTERNAL field-coil junction**, NOT a mismarked ground: the stator has **2 field coils (4 leads)**; the **inner end of each coil is tied together** (yellow/green band) and runs via a clip to **one brush**; the **GREEN line lead (red band) runs to the other brush**; the **two coils' outer ends are the BLACK and WHITE leads** (the reversing pair to the rheostat). The chassis safety ground is a separate ring-lug bond (W-6), not this junction. *(Open-source caveat: yellow/green is reserved for Protective-Earth by convention, so the published wiring note should call out that this band is an internal coil-tie marker to avoid confusion.)*
- **Provenance:** (CONFIRMED) as-performed 2026-06-23.
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

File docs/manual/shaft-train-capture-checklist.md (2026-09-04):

# Shaft Train Capture Checklist — top to bottom
### L&R Master Watch Cleaning Machine, S/N 13505

> **REPRODUCTION DOCUMENT** — Not an original L&R Mfg. Co. technical publication. Reverse-engineered from hands-on restoration of specimen S/N 13505. Curated by Hobbs R.E., 2026. For restoration reference only.

**Goal:** make the *entire rotating assembly* a complete, dimensioned BOM — not just the motor. Walk the shaft **top (basket) → bottom (lower journal)** and capture every part that mounts on or is driven by it. Prompted by the ARM-010 discovery: if one internal washer was missed, shaft-mounted parts are likely uncatalogued.

**Provenance tags** (same system as the dimension dataset): **(CONFIRMED)** caliper/tape · **(EST.)** from photo · **(SYN)** derived · **(PROVISIONAL)** existence assumed, not yet verified.

**Per-part capture fields:** Part ID · canonical name · exists? (Y/N) · mounts to / driven by · key dims (OD, height/length, bore ID, thread, mesh size) · how retained (nut/pin/press/slip) · provenance · photo ref.

---
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

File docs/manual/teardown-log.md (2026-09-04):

# Motor Teardown Log — L&R Master Watch Cleaning Machine, S/N 13505

> **REPRODUCTION DOCUMENT** — Not an original L&R Mfg. Co. technical publication. Reverse-engineered from hands-on restoration of specimen S/N 13505. Curated by Hobbs R.E., 2026. For restoration reference only.

**What this is:** the as-performed disassembly sequence, reconstructed by the restorer. It is the source for the Part III *Restoration* reassembly procedures (read in reverse for reassembly). See [`manual-outline.md`](manual-outline.md).
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

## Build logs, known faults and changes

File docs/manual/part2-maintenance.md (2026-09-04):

# Part II — Maintenance & Service
### L&R Master Watch Cleaning Machine · Master · S/N 13505

> **REPRODUCTION DOCUMENT** — Not an original L&R Mfg. Co. technical publication. Reverse-engineered from specimen S/N 13505 by Hobbs R.E., 2026. For reference only.

*Title block: Date June 12, 2026 · L&R Precision Cleaning Machine · Master · S/N 13505 · L&R MFG. CO. · Engineer Hobbs R.E.*

> ⚠️ **Best-judgment procedures.** No original L&R service sheet was available; maintenance below is reconstructed from this machine's design and general practice. Intervals are guidance, not factory spec.

---

## II.0 — Safety before servicing

- **Unplug the machine before any service** — it is live whenever plugged in (the speed knob is the only on/off).
- Treat the neck loom's **green wire as LIVE** (it is a motor branch, not a ground).
- After electrical work, run the **Stage-0 cold-checks** (II.4) before powering up.

---

## II.1 — Lubrication (the oiling system)

This is the **early oiled-bearing generation** — the sleeve bearings (BRG-001/002) are fed by a wool-yarn/felt wick system from an oil reservoir, **not** sealed-for-life. They need periodic oil.

- **Upper bearing:** lift the silver **"OIL" cap (UH-011)** on top of the motor dome and put a few drops of light machine oil (**Bramec Zoom Spout** or equivalent) onto the felt pad beneath it. Oil wicks down the internal yarn to the shaft. Replace the cap.
- **Lower bearing:** oil is fed through the wick/felt reservoir at the lower housing; add a few drops at the oil-wick port.
- **Frequency:** a few drops before extended use, or periodically with regular use. **Do not over-oil** — excess migrates onto the commutator/brushes.
- **Oil type:** light machine/turbine oil only. **Never oil the rubber jar seal** — condition rubber with silicone (Part III, III.2.2), never petroleum.

> The felt/yarn wicks must stay oil-saturated for the capillary feed to work. If a bearing runs dry or noisy, re-service the wick pack (Part III, III.3).

---

## II.2 — Brushes & commutator

The motor is a **brushed universal motor** — the carbon brushes are a wear item.

- **Access:** the two brush caps (**UH-004**) on the sides of the upper housing unscrew to withdraw each brush.
- **Inspect** for length (replace when worn short), free movement in the holder, and good spring tension. Keep spare carbon brushes on hand.
- **Commutator:** should be smooth and light-brown. Normal operation shows a small spark at the brushes, especially on start-up. **Heavy, continuous sparking or a ring of fire at steady speed** means service is due: clean the commutator (fine abrasive / commutator stick, clear the mica grooves between segments) and check brush seating.
- **After a rebuild**, new brushes spark more until they bed in to the commutator's curve — this settles with run time.

> ⚠️ Brush sparking is an ignition source — another reason for non-flammable solutions + ventilation (Part I, I.4).

---

## II.3 — Cleaning & finish care

- **Wrinkle finish (body + housings):** wipe with a soft cloth; blow dust from the texture. A light coat of **micro-crystalline wax (e.g. Renaissance Wax)**, buffed, protects and deepens the black without gloss. **Do not use WD-40 or oily dressings** on the finish — they go blotchy and attract dust.
- **Chrome (post/hardware):** wipe clean; wax lightly to protect. No abrasive polish on the plating.
- **Jewel/glass:** microfiber + a little glass cleaner; do not wax the lens face.
- **Jars & seal:** rinse jars between fluid changes; keep the rubber seal (PLT-002) pliable (silicone).

---

## II.4 — Electrical service & cold-checks

The control unit was rewired to a modern grounded standard — see the **as-built schematic `drawings/electrical/LR-ELEC-003`** (and the as-found `LR-ELEC-002` for the original circuit).

- **Junctions are serviceable:** the distribution nodes use **Wago 221 lever connectors** — open a lever to probe or re-land a wire without cutting. The rheostat's two lugs are the only soldered joints.
- **Color code:** BLACK hot · WHITE neutral · **GREEN ground only** · RED motor forward · BLUE motor reverse · YELLOW motor speed/common · **RED-with-band** heater/lamp return. (The motor loom keeps legacy colors; its green lead is a **live common**, banded red at its junction — not a ground.)
- **Pilot bulb:** a 120 V / 6 W lamp in parallel with the heater; if it fails the heater still works (independent pilot, not a fuse). Replace like-for-like.

**Stage-0 cold-checks (cord UNPLUGGED, DMM) — run after any electrical service, before power-on:**
1. Ground pin ↔ bare chassis: **≤ 0.2 Ω**.
2. Hot ↔ chassis · Neutral ↔ chassis · Ground ↔ hot · Ground ↔ neutral: all **O.L. (open)**.
3. All-off: hot ↔ neutral **O.L.**; rheostat on = motor winding + rheostat (drops as knob advances); toggle on = **≈ 220 Ω** (heater ∥ pilot).

**First power-up after service:** rheostat at OFF, ideally through a dim-bulb tester + GFCI; sweep the speed up as a soft-start.

---

## II.5 — Troubleshooting

| Symptom | Likely cause | Action |
|---|---|---|
| Motor won't start | Speed knob at OFF; no power; GFCI tripped; dry/stiff bearing | Sweep knob up from OFF; check outlet/GFCI; oil bearings; check brushes |
| Motor hums but won't turn | Only one field lead energized / a broken motor-leg connection | Check the motor-leg Wago joins (a Wago open removes a leg); verify with the schematic |
| Runs one direction only | Reverse (plunger) leg open | Check the plunger switch + its Wago/loom junction |
| Heavy sparking / ring of fire at commutator | Worn brushes, dirty/rough commutator | Service brushes + commutator (II.2) |
| No heat / drying chamber cold | Toggle off; heater branch open; R1 or connection fault | Toggle on (jewel should light); cold-check the heater branch (~220 Ω); re-seat the return Wago |
| Pilot lamp dark but heater works | Bulb burned out (independent pilot) | Replace the 120 V/6 W bulb |
| Bearing noisy / shaft binds | Reservoir wick dry; contamination | Oil the wick (II.1); if persistent, re-service the wick pack (Part III) |
| Fluid splashing out of the jar | Jar seal (PLT-002) hardened or mis-seated | Recondition/reseat the rubber seal (silicone) |
| GFCI trips on power-up | Ground fault in the wiring | Stop; re-run Stage-0 cold-checks; find the fault before retrying |

---

## II.6 — Reference

- **Wiring:** `drawings/electrical/LR-ELEC-003` (as-built) · `LR-ELEC-002` (as-found).
- **Mechanical drawings:** `drawings/components/` + `drawings/exploded/` (full motor + base package).
- **Parts:** Parts Dictionary + dimension CSVs in `docs/dimensions/`.
- **Full restoration detail:** `restoration-log.md`, `teardown-log.md`, and Part III of this manual.

---
*Maintenance intervals are guidance; adjust to use. Confidence labels per the Document Production Standards.*
